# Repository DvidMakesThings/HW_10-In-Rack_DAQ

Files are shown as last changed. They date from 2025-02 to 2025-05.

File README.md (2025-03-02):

# DataForge-Pi - The Raspberry integrated DAQ Project



## Introduction

In the current market, finding a DAQ specifically designed for 10-inch racks is quite challenging. Most available options are tailored for 19-inch racks, which are significantly larger and not suitable for more compact setups. Recognizing this gap, I embarked on a project to create a DAQ solution that fits perfectly in a 10-inch rack while still providing all the necessary features and functionalities. The goal of this project is not only to address the size constraints but also to keep the costs low and make the design accessible to everyone. 

## Development Phases

| Phase | Status |
| --- | --- |
| **PCB Design & Prototyping** |  |
| **Design Review** |  |
| **Enclosure Design** |  |
| **Order PCB** |  |
| **Prototyping and Hardware Testing** |  |
| **Initial Firmware Development** |  |
| **Enclosure Testing & Ventilation**  |  |
| **Web-Based UI for Control** |  |
| **Power Logging & Alerts** |  |
| **Production Optimization** |  |

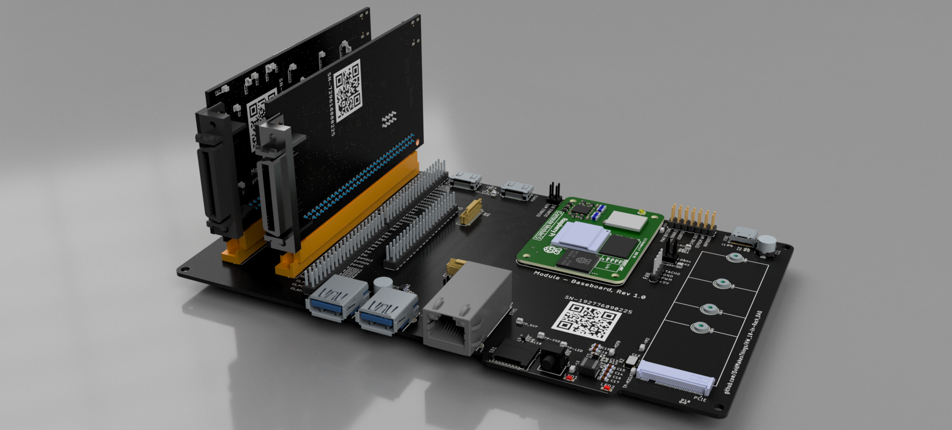
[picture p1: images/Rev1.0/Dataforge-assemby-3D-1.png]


## Features

Key features of the CM5 are as follows (for more details, refer to the [CM5 datasheet](docs/Datasheets/Raspberry-CM5_Datasheet.pdf)):

- Broadcom BCM2712, quad core Cortex-A76 (ARMv8) 64-bit SoC @ 2.4GHz
- Small Footprint 55mm × 40mm × 4.7mm module
  - 4 × M2.5 mounting holes
- 4kp60 HEVC decoder
- OpenGL ES 3.1 graphics, Vulkan 1.2
- Options for 2GB, 4GB, or 8GB LPDDR4-4267 SDRAM with ECC (see Appendix D)
- Options for 0GB (CM5Lite), 16GB, or 32GB eMMC flash memory (see Appendix D)
  - Peak eMMC bandwidth 400MBps (four times faster than previous Compute Modules)
- Option (see Appendix D) for certified radio module with:
  - 2.4 GHz, 5.0 GHz IEEE 802.11 b/g/n/ac wireless
  - Bluetooth 5.0, BLE
  - On board electronic switch to select between PCB trace or external antenna
- Gigabit Ethernet PHY supporting IEEE 1588
- 1 × PCIe 1-lane Host, Gen 2 (5Gbps)
- 1 × USB 2.0 port (high speed)
- 2 × USB 3.0 ports, supporting simultaneous 5Gbps operation
- Up to 30 × GPIO supporting either 1.8V or 3.3V signalling and peripheral options:
  - Up to 5 × UART
  - Up to 5 × I2C
  - Up to 5 × SPI
  - 1 × SDIO interface
  - 1 × DPI (parallel RGB display)
  - 1 × I2S
  - Up to 4 × PWM channels
  - Up to 3 × GPCLK outputs
- 2 × HDMI 2.0 ports (supports up to 4Kp60 on each port simultaneously)
- 2 × 4-lane MIPI ports
  - Supporting both DSI (display port) and CSI-2 (camera port)
- 1 × SDIO 2.0 (CM5Lite)
- Single +5V PSU input supports USB PD for up to 5A @ 5V
- Real-time clock (RTC), powered from external battery

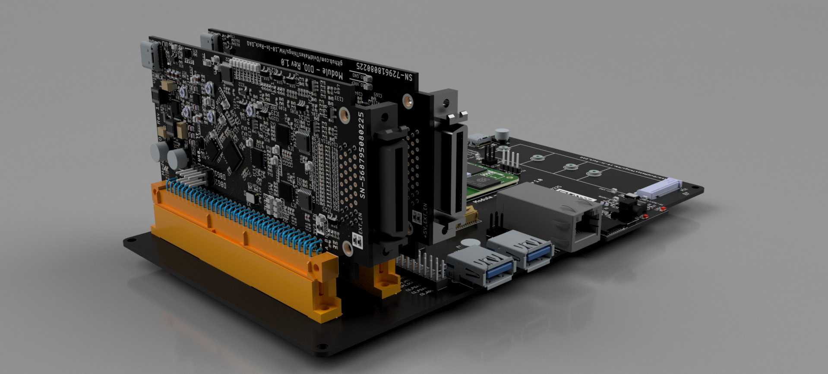
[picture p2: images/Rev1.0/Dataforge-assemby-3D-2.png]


## DAQ Specifications

### Analog Input (16 Channels)

The analog input section of the DAQ system is designed to provide high precision and flexibility for various applications. It features 16 channels of analog input, each capable of high-resolution data acquisition.

**Key Components:**
- **External 14-bit ADC:** The ADS9234RIRHBR is a 14-bit, 3.5-MSPS dual SAR ADC with simultaneous sampling, internal reference, and enhanced SPI, ensuring accurate and reliable measurements.
- **Multiplexers:** 2 × DG409 are employed for flexible channel selection, allowing the system to switch between different input channels efficiently.
- **Programmable Gain Amplifiers (PGA):** ADA4254ACPZ are used to provide scalable input ranges, enabling the system to handle a wide variety of signal amplitudes.

### Analog Output (8 Channels)

The analog output section is designed to provide precise and stable output signals. It features 8 channels of analog output, each capable of high-resolution signal generation.

**Key Components:**
- **External 16-bit DAC:** The DAC8568 is used for precision outputs, ensuring accurate and stable signal generation.
- **Operational Amplifiers:** TLV2372 are used for buffering and output stability, providing reliable and consistent performance.

### Digital IO (32 Channels)

The digital IO section is designed to provide versatile and robust digital input and output capabilities. It features 32 channels of digital IO, each capable of handling various voltage levels and signal types.

**Key Components:**
- **Bidirectional Voltage-Level Translators:** LSF0108-Q1 are used for multi-voltage compatibility, allowing the system to interface with different voltage levels.
- **Direct GPIO Support:** The RP2040 provides simple and robust design for direct GPIO support, ensuring reliable digital IO performance.

### Constants

- **ADC Sampling Rate:** 3.5 MSPS (Maximum sampling rate of ADS9234R)
- **ADC Nyquist Limit:** 1.75 MHz (Nyquist bandwidth for ADC)
- **PGA Bandwidth:** 10 MHz (Maximum bandwidth of ADA4254 at Gain = 1)
- **DG409 Transition Time:** 160 ns (Transition time for DG409)
- **ADA4254 Transition Time:** 200 ns (Transition time for ADA4254)

### Bandwidth for Each Gain Setting

The bandwidth for each gain setting is determined by the combination of the ADC's Nyquist limit and the PGA's frequency response. For gains less than or equal to 1, the bandwidth is capped by the ADC's Nyquist limit. For gains greater than 1, the bandwidth is limited by the PGA's frequency response.

- **Gain = 1/16:** Bandwidth = 1.75 MHz (Capped by ADC)
- **Gain = 1/8:** Bandwidth = 1.75 MHz (Capped by ADC)
- **Gain = 1/4:** Bandwidth = 1.75 MHz (Capped by ADC)
- **Gain = 1/2:** Bandwidth = 1.75 MHz (Capped by ADC)
- **Gain = 1:** Bandwidth = 1.75 MHz (Capped by ADC)
- **Gain = 2:** Bandwidth = 1.75 MHz (Capped by ADC)
- **Gain = 4:** Bandwidth = 1.75 MHz (Capped by ADC)
- **Gain = 8:** Bandwidth = 1.25 MHz (PGA Limited)
- **Gain = 16:** Bandwidth = 625 kHz (PGA Limited)
- **Gain = 32:** Bandwidth = 312.5 kHz (PGA Limited)
- **Gain = 64:** Bandwidth = 156.25 kHz (PGA Limited)
- **Gain = 128:** Bandwidth = 78.125 kHz (PGA Limited)

### Notes

- For Gains ≤ 1, bandwidth is capped by ADC's Nyquist limit (1.75 MHz).
- For Gains > 1, bandwidth is limited by the PGA's frequency response.
- Transition delays (DG409 + ADA4254) are factored into the calculation.

### Input Ranges for Different Gains

The input ranges for different gain settings are determined by the reference voltage (VREF), positive supply voltage (V+), and negative supply voltage (V-). For this system, VREF is set to 2.5V, V+ is set to +12V, and V- is set to -12V.

| Gain | Differential Input Range (±V) | Positive Input Range (0 to V) | Negative Input Range (0 to -V) | Max Bandwidth (Hz) |
|---|---|---|---|---|
| 1/16 | ±80.0 | 0 to 40.0 | 0 to -40.0 | 1,750,000 |
| 1/8  | ±40.0 | 0 to 20.0 | 0 to -20.0 | 1,750,000 |
| 1/4  | ±20.0 | 0 to 10.0 | 0 to -10.0 | 1,750,000 |
| 1/2  | ±10.0 | 0 to 5.0 | 0 to -5.0 | 1,750,000 |
| 1 | ±5.0 | 0 to 2.5 | 0 to -2.5 | 1,750,000 |
| 2 | ±2.5 | 0 to 1.25 | 0 to -1.25 | 1,750,000 |
| 4 | ±1.25 | 0 to 0.625 | 0 to -0.625 | 1,750,000 |
| 8 | ±0.625 | 0 to 0.3125 | 0 to -0.3125 | 1,250,000 |
| 16 | ±0.3125 | 0 to 0.15625 | 0 to -0.15625 | 625,000 |
| 32 | ±0.15625 | 0 to 0.078125 | 0 to -0.078125 | 312,500 |
| 64 | ±0.078125 | 0 to 0.0390625 | 0 to -0.0390625 | 156,250 |
| 128  | ±0.0390625 | 0 to 0.01953125 | 0 to -0.01953125 | 78,125 |

## Getting Started

Refer to the datasheets and manuals in the `docs` folder for detailed information on the components and usage instructions.

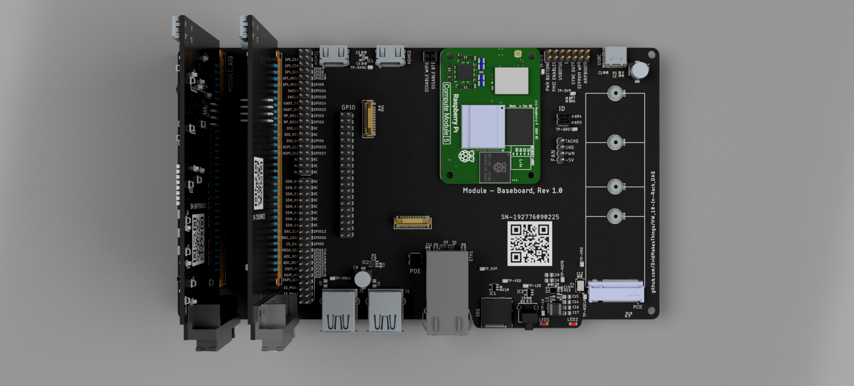
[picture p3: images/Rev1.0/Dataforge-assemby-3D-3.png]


## License

This project is licensed under the GPL3 License. See the LICENSE file for details.

## Contact

For questions or feedback:

- Email: s.dvid@hotmail.com
- GitHub: [DvidMakesThings](https://github.com/DvidMakesThings)

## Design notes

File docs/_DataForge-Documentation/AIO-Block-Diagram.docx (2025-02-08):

+12V -12V

+5V +3.3V

0-5V OUT

+/-12V OUT

BUFFER

IN

OUT

BUFFER

IN

OUT

+/- IN0-7

+/- IN8-15

DAC

DAC-IO
SPI

OUT 0-3
OUT 4-7

VREF

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
VREF

+12V -12V +3.3V

ANALOG SW

OUT
DIO

IN

ANALOG SW

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
MISO SEL

SEL

SDOA
SDOB

MISO

RP2040

ADC-IO

SPI0

SDO

MISO-SEL

DAC-IO

DEBUG

SPI1

ADC

VBUS
+12V
-12V
+5V

UART0
SWIO

GPIO INTERFACE

DEBUG

SPI1

ADC-IO

SPI0

SDO

SEL

DAC-IO

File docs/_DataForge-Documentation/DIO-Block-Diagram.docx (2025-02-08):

+5V SUPPLY

+3.3V SUPPLY

GPIO INTERFACE

DEBUG

SPI1

LEVEL SEL

SPI0

DIO-RST

DIO-EN

UART0
SWIO

+5V SUPPLY

VBUS

LEVEL SEL

LS

+5V

+3.3V

OUT

DIOH

SPI

RST

OUT

LEVEL TRANSLATOR

EN

IN

VREF

OUT

LEVEL TRANSLATOR

EN

IN

VREF

OUT

LEVEL TRANSLATOR

EN

IN

VREF

OUT

LEVEL TRANSLATOR

EN

IN

VREF

OUT

RP2040

LEVEL SEL

SPI0

DIO-RST

DIO-EN

DEBUG

SPI1

ADC

DIOL

SPI

RST

OUT

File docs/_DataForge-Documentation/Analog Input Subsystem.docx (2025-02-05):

# Analog Input Subsystem

# 1. Introduction

This document provides a detailed overview of the Analog Input (AI) subsystem of the DAQ system, focusing on signal acquisition, amplification, filtering, and communication with the ADC. It covers key components, signal flow, and considerations for optimal performance.

# 2. System Overview

The Analog Input Subsystem consists of:

- 16 Differential Analog Inputs (AI)
- Programmable Gain Amplifiers (PGA) for signal conditioning
- Multiplexers for channel selection
- High-speed 14-bit ADC for conversion
- SPI communication for data transfer
- Power distribution and filtering

# 3. Analog Input (16 Channels)

The analog input section of the DAQ system is designed to provide high precision and flexibility, capable of acquiring signals from various sources.

## 3.1 Key Components

- External 14-bit ADC: ADS9234RIRHBR, a 14-bit, 3.5-MSPS dual SAR ADC with simultaneous sampling, internal reference, and enhanced SPI for high-speed acquisition.
- Multiplexers: 2 × DG409 for channel selection, enabling flexible signal routing to the ADC.
- Programmable Gain Amplifiers (PGA): ADA4254ACPZ for scalable input ranges, ensuring adaptability to different signal levels.

## 3.2 ADC Communication & Control

- SPI Interface:
  - SCLK (Clock Signal)
  - MOSI (Master Out Slave In)
  - MISO (Master In Slave Out)
  - CS (Chip Select)
- Control Signals:
  - ADC_RDY: Data ready indication
  - ADC_RST: Reset signal
  - MISO_SEL: Selects the correct SPI MISO line

## 3.3 Analog Input Switching Mechanism (Differential and Single-Ended Mode)

To maximize the flexibility of the system while maintaining accurate signal acquisition, a DG409 multiplexer is used to route the selected input signal to the ADA4254 programmable gain amplifier (PGA) before being fed into the ADS9234 ADC.

Each DG409 consists of four normally open SPST switches that can be controlled digitally. The AI+ signals are routed through the upper switch bank, while the corresponding AI- signals are routed through the lower switch bank. For differential measurements, both AI+ and AI- channels are selected. For single-ended measurements, either AI+ or AI- can be selected, while the unselected input is connected to ground.

## 3.4 Channel Selection Control (Differential and Single-Ended)

The DG409 multiplexer allows the selection of one of four differential input pairs or a single-ended configuration. The selection is made via two digital control inputs (A0, A1), which follow the logic below:

Differential Input Mode Single-Ended Input Mode

A1 | A0 | Selected AI+ / AI- Pair
0 | 0 | AI1+ / AI2-
0 | 1 | AI3+ / AI4-
1 | 0 | AI5+ / AI6-
1 | 1 | AI7+ / AI8-

A1 | A0 | Selected Input | Other Input
0 | 0 | AI1+ or AI2- | GND
0 | 1 | AI3+ or AI4- | GND
1 | 0 | AI5+ or AI6- | GND
1 | 1 | AI7+ or AI8- | GND

By setting the control signals A0 and A1 correctly, any of the available differential or single-ended inputs can be connected to the PGA and ADC. The multiplexer transitions occur within 160ns, ensuring minimal signal delay.

## 3.5 Software Control of Channel Selection

In the software, the channel selection is managed by setting the GPIO pins connected to the DG409 control inputs (A0, A1). The selection process follows these steps:

1. Disable Data Acquisition: Before switching channels, the ADC sampling process is halted to prevent incorrect readings during transitions.
2. Set Multiplexer Control Lines: The microcontroller sets the GPIO pins corresponding to A0 and A1 based on the required channel.
3. Configure for Single-Ended or Differential Mode: If single-ended mode is selected, the corresponding AI- or AI+ input is connected to ground in software.
4. Delay for Settling Time: A short delay (~200ns) is introduced to allow the multiplexer switches to stabilize.
5. Enable Data Acquisition: Once the multiplexer output has stabilized, ADC sampling resumes.

This function allows dynamic switching between differential and single-ended configurations, with the ability to choose whether AI+ or AI- is used as the active signal.

## 3.6 PGA and ADC Interaction

Once a selected differential input signal is passed through the DG409 multiplexer, it is fed into the ADA4254 programmable gain amplifier (PGA). The gain of the PGA can be controlled dynamically based on system requirements to optimize signal-to-noise ratio before it is sent to the ADS9234 ADC for digitization.

## 3.7 Bandwidth for Each Gain Setting

The bandwidth is determined by the ADC's Nyquist limit and the PGA's frequency response. Lower gains maintain the ADC's full bandwidth, while higher gains are limited by the PGA.

Gain | Max Bandwidth (Hz)
1/16 | 1,750,000
1/8 | 1,750,000
1/4 | 1,750,000
1/2 | 1,750,000
1 | 1,750,000
2 | 1,750,000
4 | 1,750,000
8 | 1,250,000
16 | 625,000
32 | 312,500
64 | 156,250
128 | 78,125

## 3.8 Input Ranges for Different Gains

The input ranges are defined by the reference voltage (VREF = 2.5V), positive supply voltage (+12V), and negative supply voltage (-12V).

Gain | Differential Input Range (±V) | Positive Input Range (0 to V) | Negative Input Range (0 to -V)
1/16 | ±80.0 | 0 to 40.0 | 0 to -40.0
1/8 | ±40.0 | 0 to 20.0 | 0 to -20.0
1/4 | ±20.0 | 0 to 10.0 | 0 to -10.0
1/2 | ±10.0 | 0 to 5.0 | 0 to -5.0
1 | ±5.0 | 0 to 2.5 | 0 to -2.5
2 | ±2.5 | 0 to 1.25 | 0 to -1.25
4 | ±1.25 | 0 to 0.625 | 0 to -0.625
8 | ±0.625 | 0 to 0.3125 | 0 to -0.3125
16 | ±0.3125 | 0 to 0.15625 | 0 to -0.15625
32 | ±0.15625 | 0 to 0.078125 | 0 to -0.078125
64 | ±0.078125 | 0 to 0.0390625 | 0 to -0.0390625
128 | ±0.0390625 | 0 to 0.01953125 | 0 to -0.01953125

# 4. Power Subsystem for Analog Input

## 4.1 Power System Overview

The analog input subsystem requires multiple voltage levels to operate correctly. The ADC and SPI communication rely on a stable 3.3V power rail, while the PGA and analog input circuits need ±12V for proper operation. To generate these voltages, a combination of a boost converter and LDO regulators is used.

## 4.2 Boost Converter (5V to ±14V)

The TPS65131 is a dual-output DC-DC converter that efficiently converts a 5V input to ±14V, ensuring stable and isolated power for the high-performance analog circuits. The positive and negative voltage rails are generated using a single inductor topology, reducing PCB space and complexity. The output is stabilized using low-ESR capacitors (22µF and 10µF), ensuring minimal ripple.

## 4.3 LDO Regulation (±14V to ±12V)

The ±14V rails generated by the boost converter are further regulated using the TPS7A39, a precision low-noise LDO regulator. This step ensures that the analog circuits receive clean and low-ripple ±12V supplies. The regulator uses bulk 22µF capacitors for stable operation, with 100nF decoupling capacitors placed near the power pins of the PGA and ADC to prevent noise coupling.

## 4.4 Power Distribution Considerations

To ensure optimal performance, the power system is designed with:

- Separate ground planes for analog and digital sections to minimize interference.
- High-frequency decoupling capacitors near ICs to suppress transient noise.
- Low dropout regulators to improve power efficiency and thermal management.
- Current limiting and ESD protection at the power input to prevent damage from transient spikes or electrical surges.

# 5. Summary

This document focuses exclusively on the Analog Input Subsystem of the DAQ system, covering:

- 16 AI differential inputs with signal conditioning.
- PGA and multiplexer configurations for flexible input selection.
- SPI-based ADC communication and control logic.
- A well-structured power system, including boost conversion and LDO regulation.

This modular approach ensures seamless integration into the full DAQ system while maintaining signal integrity and accuracy.

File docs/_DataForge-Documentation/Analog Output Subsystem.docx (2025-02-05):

# Analog Output Subsystem:

# OPA192 & OPA197 Integration

# 1. Introduction

This document presents a detailed design for the analog output stage of a Data Acquisition (DAQ) system, ensuring accurate signal conditioning, stability, and robustness.

The DAQ outputs are classified into two voltage stages:

- DAC0-3 (3.3V Stage)
  - Uses OPA192 as the buffer op-amp.
  - Output range: 0V to 3.3V.
- DAC4-7 (±12V Stage)
  - Uses OPA197 for high-voltage amplification.
  - Output range: -12V to +12V.

## 1.1. Design Objectives

The core objectives of this design include:

1. Accurate DAC output scaling
2. Ensuring stability with capacitive loads
3. Consistent bandwidth (~100 kHz) across both stages
4. Minimized voltage drop across R_ISO
5. Optimized resistor values for precise scaling

# 2. DAC8568 Output Scaling for 3.3V and ±12V Stages

The DAC8568 generates a 0V to 2.5V output, which must be amplified and shifted to match the respective voltage stages.

## 2.1. Output Calculation

For a generalized output scaling formula, the output voltage is given by:

V_(OUT) =(1+(R_(FB))/(R_(G2))+(R_(FB))/(R_(G1)))V_(DAC) -((R_(FB))/(R_(G2)))V_(REF)

Where:

- V_(DAC) = DAC output voltage (0 to 2.5V)
- V_(REF) = 2.5V DAC reference
- R_(FB) = Feedback resistor
- R_(G1) , R_(G1) = Gain resistors

The resistor network is designed separately for each voltage stage.

# 3. DAC8568 Output Scaling for 3.3V Stage

The 3.3V stage (DAC0-3) uses OPA192 in a non-inverting amplifier configuration.

## 3.1. Gain Calculation

The gain is:

G=(V_(OUT_(max)) -V_(OUT_(min)))/(V_(DAC_(max)) -V_(DAC_(min)))

G=(3.3V-0V)/(2.5V-0V)=1.32

## 3.2. Resistor Selection

For a non-inverting amplifier, the gain is:

G=1+(R_F)/(R_G)

Choosing R_G =10kΩ :

1.32=1+(R_F)/(10kΩ)

R_F =(1.32-1) ∙10kΩ=3.2kΩ

## 3.3. Output Resolution Calculation

- DAC resolution:

Resolution_(DAC) =(V_(REF))/(2^16)=(2.5V)/65536≈0.038mV

- Scaled output resolution:

Resolution_(OUT) = Resolution_(DAC) ∙G=0.038mV∙1.32 ≈0.05mV

## 3.4. Final Resistor Values

Component | Value
R_F | 3.2kΩ
R_G | 10kΩ

# 4. DAC8568 Output Scaling for ±12V Stage

The ±12V stage (DAC4-7) uses OPA197 to achieve high-voltage amplification.

## 4.1. Gain Calculation

The gain is:

G=(V_(OUT_(max)) -V_(OUT_(min)))/(V_(DAC_(max)) -V_(DAC_(min)))

G=(12V-(-12V))/(2.5V-0V)=(24V)/(2.5V)=9.6

## 4.2. Resistor Selection

For a non-inverting amplifier, the gain is:

G=1+(R_F)/(R_G)

Choosing R_G =10kΩ :

9.6=1+(R_F)/(10kΩ)

R_F =(9.6-1) ∙10kΩ=86kΩ

## 4.3. Output Resolution Calculation

Scaled output resolution:

Resolution_(OUT) = Resolution_(DAC) ∙G=0.038mV∙9.6 ≈0.3648mV

## 4.4. Final Resistor Values

Component | Value
R_F | 86kΩ
R_G | 10kΩ

# 5. Stability Considerations

## 5.1. OPA192 (3.3V Stage)

- Low-power op-amp with 1 MHz GBW.
- Requires R_(ISO) for stability with higher capacitive loads.
- Chosen values:
  - R_(ISO) =68Ω
  - C_(LOAD) =20nF

## 5.2. OPA197 (±12V Stage)

- Precision op-amp with 2.5 MHz GBW.
- Stabilized by R_ISO for capacitive loads.
- Chosen values:
  - R_(ISO) =110Ω
  - C_(LOAD) =12nF

# 6. Load Stability & Voltage Drop Analysis

The cutoff frequency for stability is:

f_c =1/(2 π R_(ISO) C_(LOAD))

For the 3.3V stage:

f_c =1/(2∙π∙ 68 ∙20nF)≈117 kHz

For the ±12V stage:

f_c =1/(2∙π∙110 ∙12nF)≈120 kHz

Voltage drop across R_(ISO) :

V_(drop) =I_(load) ∙R_(ISO)

For 5mA output current:

- OPA192 (3.3V Stage, R_(ISO) =68Ω )

V_(drop_(3V3)) =5mA∙68Ω=0.34V

- OPA197 (±12V Stage, R_(ISO) =110Ω )

V_(drop_(12V)) =5mA∙110Ω=0.55V

# 7. Final Optimized Circuit

## 7.1. Parameter Summary

DAC Channel | Op-Amp | Supply Voltage | Output Voltage Range | R_(ISO) | C_(LOAD) | Cutoff Frequency (kHz)
DAC0-3 | OPA192 | 5V | 0V to 3.3V | 68Ω | 20nF | 117 kHz
DAC4-7 | OPA197 | ±12V | -12V to +12V | 110Ω | 12nF | 120 kHz

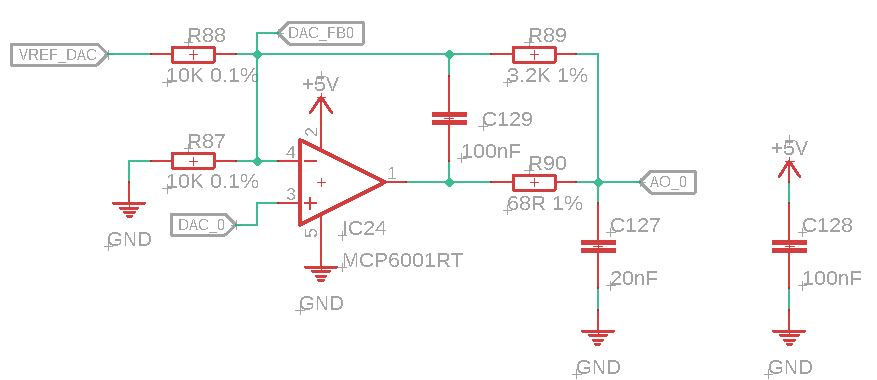
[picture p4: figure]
A képen diagram, szöveg, sor, Diagram látható Előfordulhat, hogy a mesterséges intelligencia által létrehozott tartalom helytelen.
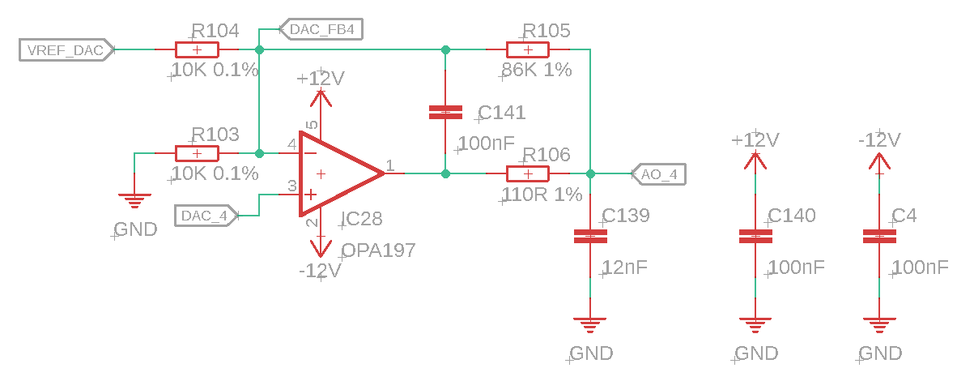
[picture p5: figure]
A képen diagram, szöveg, sor, Tervrajz látható Előfordulhat, hogy a mesterséges intelligencia által létrehozott tartalom helytelen.

# 8. Purpose of the 10kΩ Pulldown Resistors

The pulldown resistors serve a critical role in ensuring signal stability by preventing the op-amp’s inverting input from floating if the DAC output becomes high impedance (tri-stated or powered down). A floating inverting input can result in:

- Op-amp instability or oscillations
- Increased noise sensitivity
- Unexpected voltage drift due to leakage currents

To evaluate whether the 10kΩ resistors are necessary, we analyze their voltage effect and impact on circuit stability for both the 3.3V and ±12V output stages.

## 8.1. Voltage Division & Leakage Current Analysis

If the DAC output enters high impedance mode (open circuit), the pulldown resistor determines the voltage at the op-amp's inverting input.

## 8.2. Calculation for the 3.3V Stage (OPA192)

- Op-amp: OPA192 (low-power, rail-to-rail, 5V single-supply)
- Pulldown resistor: R_(PD) =10kΩ
- DAC reference voltage: V_(DAC_(max)) =2.5V, V_(DAC_(min)) =0V
- Op-amp bias current (typical): I_B =1pA
- Leakage current estimate I_(leak) =10nA (conservative assumption)

Voltage at the inverting input when DAC is in high-Z mode:

V_(IN-) = R_(PD) I_(leak) =10kΩ ∙10nA=0.1mV

## 8.3. Calculation for the ±12V Stage (OPA197)

- Op-amp: OPA197 (precision, ±12V supply)
- Pulldown resistor: R_(PD) =100kΩ
- DAC reference voltage: V_(DAC_(max)) =2.5V, V_(DAC_(min)) =0V
- Op-amp bias current (typical): I_B =10pA
- Leakage current estimate I_(leak) =20nA

Voltage at the inverting input when DAC is in high-Z mode:

V_(IN-) = R_(PD) I_(leak) =100kΩ ∙20nA=2mV

## 8.4 Impact on Stability & Frequency Response

The inverting input is highly sensitive. Without the pulldown resistor:

- Any residual charge on the PCB traces could cause voltage drift.
- Leakage currents from the DAC or op-amp could accumulate, shifting the voltage.
- Noise from adjacent signals could capacitively couple into the floating node, leading to oscillations.

Adding R_(PD) prevents floating and keeps the circuit deterministic even if the DAC is disabled.

## 8.5. Power Dissipation Analysis

For continuous operation, power consumption due to the pulldown resistors is:

P=(V^2)/R

The 3.3V Stage:

P=(5V^2)/(10kΩ)=2.5mW

The ±12V Stage:

P=(12V^2)/(100kΩ)=1.44mW

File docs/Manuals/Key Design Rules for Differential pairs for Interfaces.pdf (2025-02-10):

## High-Speed Differential Pair Routing Guidelines

Interface | Type | Signal Names Pair Matching
Tolerance

Inter-Pair
Matching
Tolerance

Additional
Notes
USB 2.0 | Differential | DP_N, DP_P | ±150 mil | Not required | Keep traces short, avoid vias
USB 3.0 | Differential | SSRX_N, SSRX_P / SSTX_N, SSTX_P | ±2 mil | ±5 mil | Avoid stubs, tightly controlled impedance
USB 3.1/3.2 | Differential | SSRX_N, SSRX_P / SSTX_N, SSTX_P | ±2 mil | ±5 mil | Minimize vias, length matching critical
USB4 / Thunderbolt 3 | Differential | HSRX_N, HSRX_P / HSTX_N, HSTX_P | ±1 mil | ±3 mil | Use well- matched controlled impedance stackup
Ethernet 100BASE-TX | Differential | TD_N, TD_P / RD_N, RD_P | ±50 mil | ±100 mil | Terminate properly, avoid large trace gaps
Ethernet 1000BASE-T | Differential | TX1_N, TX1_P / TX2_N, TX2_P / TX3_N, TX3_P / TX4_N, TX4_P | ±5 mil | ±10 mil | All pairs must be matched for delay skew
Ethernet 10GBASE-T | Differential | TXA_N, TXA_P / TXB_N, TXB_P / TXC_N, TXC_P / TXD_N, TXD_P | ±2 mil | ±5 mil | Use high- quality PCB material
HDMI 1.4 | Differential | TMDS0_N, TMDS0_P / TMDS1_N, TMDS1_P / TMDS2_N, TMDS2_P / TMDS_CK_N, TMDS_CK_P | ±5 mil | ±20 mil | Keep CLK pair shorter than data pairs
HDMI 2.0 | Differential | TMDS0_N,
TMDS0_P /
TMDS1_N,
TMDS1_P /
TMDS2_N,
TMDS2_P /
±2 mil | ±10 mil | All lanes must
be lengthmatched

TMDS_CK_N,
TMDS_CK_P
DisplayPort
1.2

Differential ML0_N, ML0_P
/ ML1_N,
ML1_P /
AUX_N, AUX_P
±3 mil | ±10 mil | Minimize skew
between lanes

DisplayPort
2.0

Differential ML0_N, ML0_P
/ ML1_N,
ML1_P /
AUX_N, AUX_P
±2 mil | ±5 mil | Very strict
inter

-pair
matching
PCIe Gen1/2 | Differential | PCIE_RX_N,
PCIE_RX_P /
PCIE_TX_N,
PCIE_TX_P
±5 mil | ±20 mil | Avoid
impedance
discontinuities
PCIe Gen3 | Differential | PCIE_RX_N,
PCIE_RX_P /
PCIE_TX_N,
PCIE_TX_P
±2 mil | ±10 mil | Tighter
matching than
Gen1/2
PCIe Gen4 | Differential | PCIE_RX_N,
PCIE_RX_P /
PCIE_TX_N,
PCIE_TX_P
±1 mil | ±5 mil | Low

-loss PCB
materials
recommended
PCIe Gen5 | Differential | PCIE_RX_N,
PCIE_RX_P /
PCIE_TX_N,
PCIE_TX_P
±0.5 mil | ±2 mil | Extremely tight
tolerance, use
high

-speed
stackup
SATA 3.0 | Differential | SATA_TX_N,
SATA_TX_P /
SATA_RX_N,
SATA_RX_P
±5 mil | ±20 mil | Shortest
possible path,
avoid vias
SAS 12G | Differential | SAS_TX_N,
SAS_TX_P /
SAS_RX_N,
SAS_RX_P
±2 mil | ±5 mil | Keep
differential
impedance
strict
MIPI DSI/CSI | Differential | DSID0_N

,
DSID0_P

/
DSID1_N

,
DSID1_P

/
DSID2_N

,
DSID2_P

/
DSID3_N

,
DSID3_P

/
DSIC_N

,
DSIC_P
±2 mil | ±10 mil | Use matched trace routing for high -speed
LVDS | Differential | LVDS0_N,
LVDS0_P /
LVDS1_N,
LVDS1_P
±5 mil | ±20 mil | Terminate
correctly at
receiver

General Routing Guidelines:
1. Use an impedance calculator (based on your stackup) to determine trace width & spacing.
2. Keep differential pairs tightly coupled (avoid large gaps between P/N).
3. Minimize vias—every via adds impedance discontinuity.
4. Match each pair within tolerance to ensure proper signal integrity.
5. Inter-pair matching is critical for multi-lane interfaces (Ethernet, HDMI, PCIe, DP).
6. Avoid stubs—use direct traces whenever possible.

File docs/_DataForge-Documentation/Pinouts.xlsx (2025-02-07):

D-Sub Micro-D Connector |  | MAB64 Connector |  |  |  | RP2040
1 | V-EXT | A1 | +3.3V | B1 | +3.3V | GPIO0 | UART0_RX
2 | AI_0+ | A2 | SPI0_CS0 | B2 | SPI0_CS3 | GPIO1 | UART0_TX
3 | AI_1- | A3 | SPI0_CS1 | B3 | SPI0_SCK | GPIO2 | SPI0_SCK
4 | AI_2+ | A4 | SPI0_CS2 | B4 | SPI0_MOSI | GPIO3 | SPI0_MOSI
5 | AI_3- | A5 | SPI0_SCK | B5 | SPI0_MISO | GPIO4 | SPI0_MISO
6 | AI_4+ | A6 | SPI0_MOSI | B6 | NC | GPIO5 | SPI0_CS0
7 | AI_5- | A7 | SPI0_MISO | B7 | NC | GPIO6 | SPI0_CS1
8 | AI_6+ | A8 | +5V | B8 | +5V | GPIO7 | SPI0_CS2
9 | AI_7- | A9 | +5V | B9 | +5V | GPIO8 | ADC_RDY
10 | AI_8+ | A10 | GND | B10 | GND | GPIO9 | ADC_RST
11 | AI_9- | A11 | ADC_RDY | B11 | NC | GPIO10 | SPI1_SCK
12 | AI_10+ | A12 | ADC_RST | B12 | DAC_LDAC | GPIO11 | SPI1_MOSI
13 | AI_11- | A13 | MISO_SEL | B13 | DAC_CLR | GPIO12 | SPI1_MISO
14 | AI_12+ | A14 | GND | B14 | GND | GPIO13 | SPI1_CS
15 | AI_13- | A15 | GND | B15 | GND | GPIO14 | DAC_LDAC
16 | AI_14+ | A16 | GND | B16 | GND | GPIO15 | DAC_CLR
17 | AI_15- | A17 | SDO_A_0 | B17 | NC | GPIO16 | SDO_A_0
18 | GND | A18 | SDO_A_1 | B18 | RP2040-RST | GPIO17 | SDO_A_1
19 | GND | A19 | SDO_A_2 | B19 | GND | GPIO18 | SDO_A_2
20 | VBUS | A20 | SDO_A_3 | B20 | UART0_RX | GPIO19 | SDO_A_3
21 | AO_0 | A21 | SDO_B_0 | B21 | UART0_TX | GPIO20 | SDO_B_0
22 | GND | A22 | SDO_B_1 | B22 | GND | GPIO21 | SDO_B_1
23 | AO_1 | A23 | SDO_B_2 | B23 | SWCLK | GPIO22 | SDO_B_2
24 | GND | A24 | SDO_B_3 | B24 | SWDIO | GPIO23 | SDO_B_3
25 | AO_2 | A25 | GND | B25 | GND | GPIO24 | MISO_SEL
26 | GND | A26 | SPI1_MISO | B26 | SPI1_MISO | GPIO25 | SPI0_CS3
27 | AO_3 | A27 | SPI1_MOSI | B27 | SPI1_MOSI | GPIO26/ADC0 | ADC_VUSB
28 | GND | A28 | SPI1_SCK | B28 | SPI1_SCK | GPIO27/ADC1 | ADC_12VP
29 | AO_4 | A29 | SPI1_CS | B29 | SPI1_CS | GPIO28/ADC2 | ADC_12VN
30 | GND | A30 | GND | B30 | GND | GPIO29/ADC3 | ADC_5VP
31 | AO_5 | A31 | GND | B31 | GND
32 | GND | A32 | GND | B32 | GND
33 | AO_6
34 | GND
35 | AO_7
36 | GND

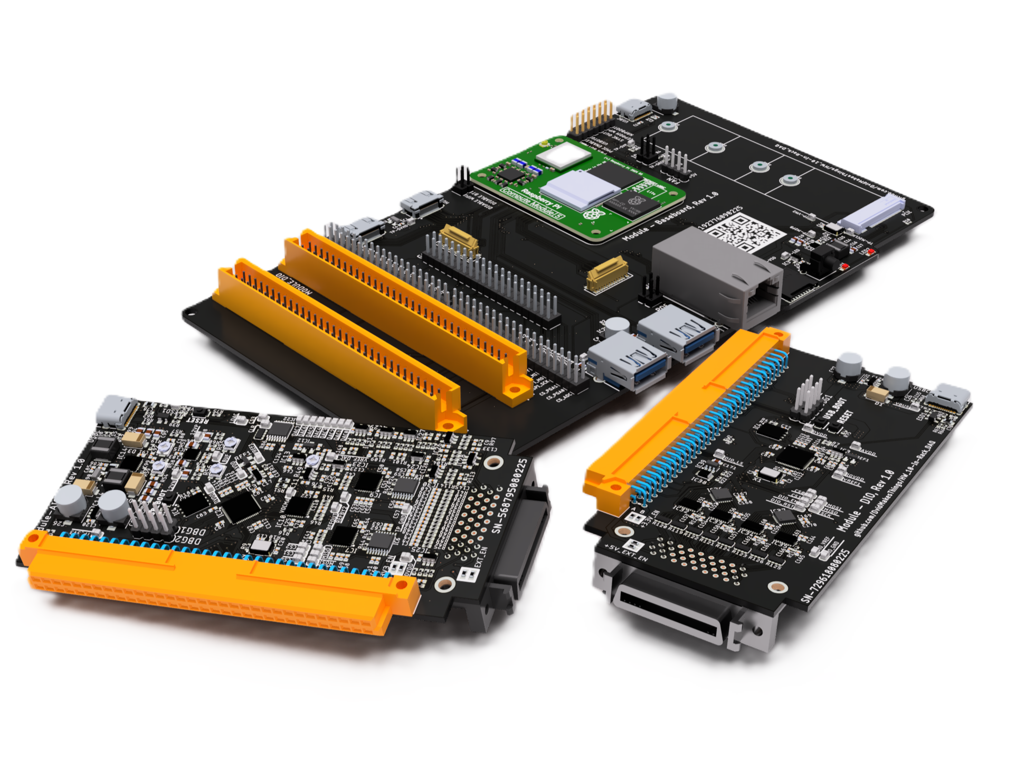
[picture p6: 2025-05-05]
images/dataforge_render1.png

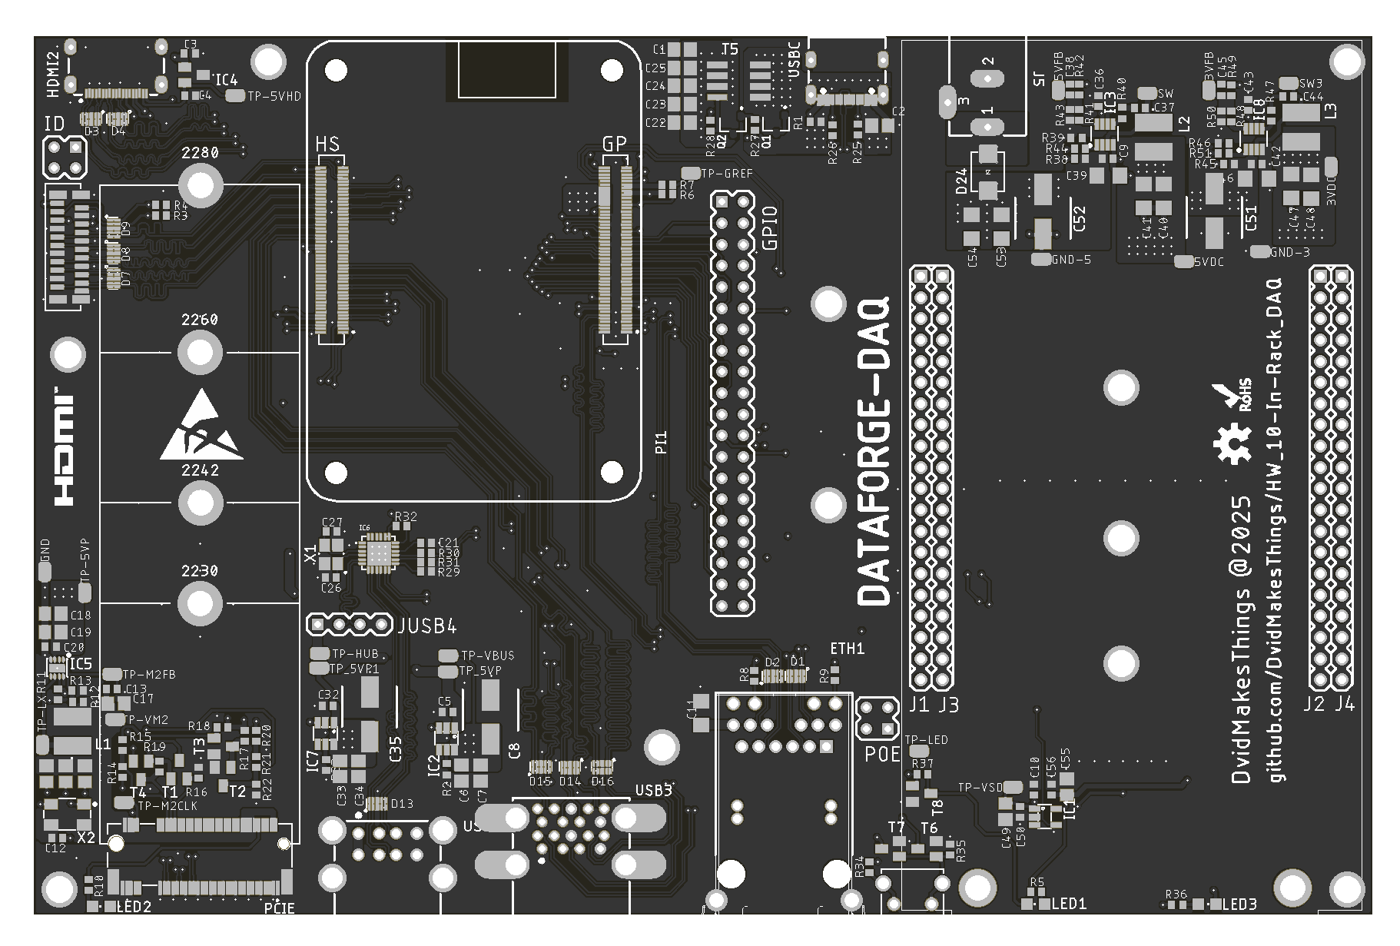
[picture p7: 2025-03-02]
images/Module_BaseBoard _2.0_Top.png

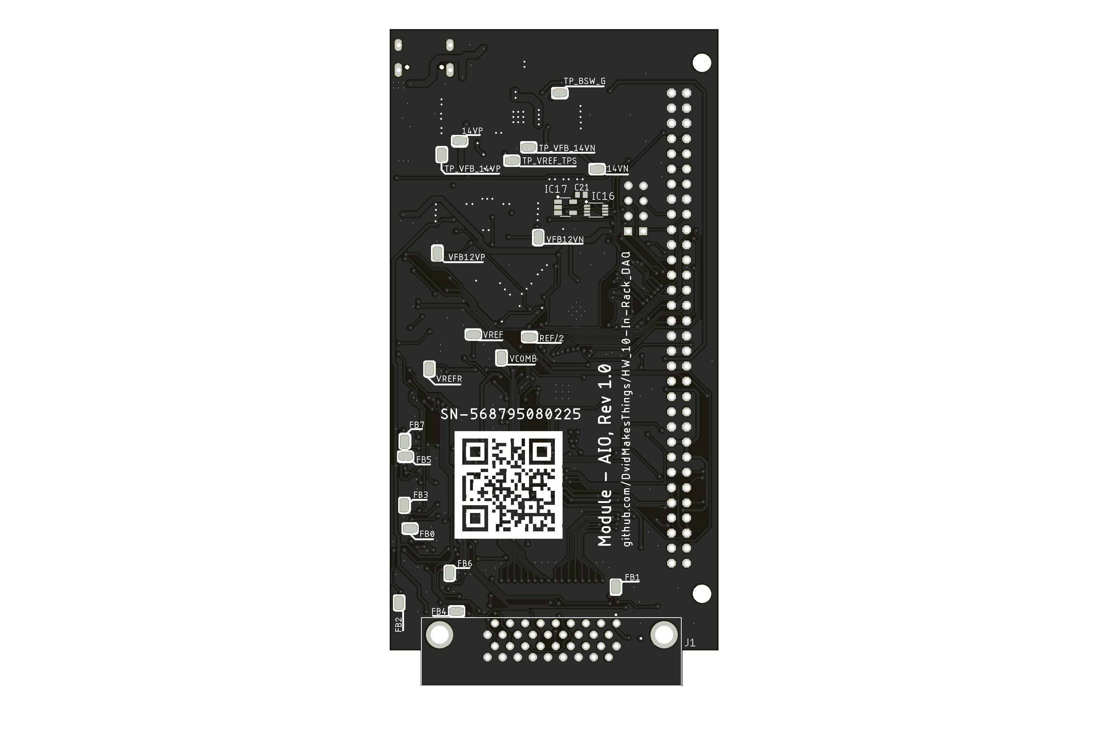
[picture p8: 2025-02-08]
images/Rev1.0/Module_AIO_bottom.png

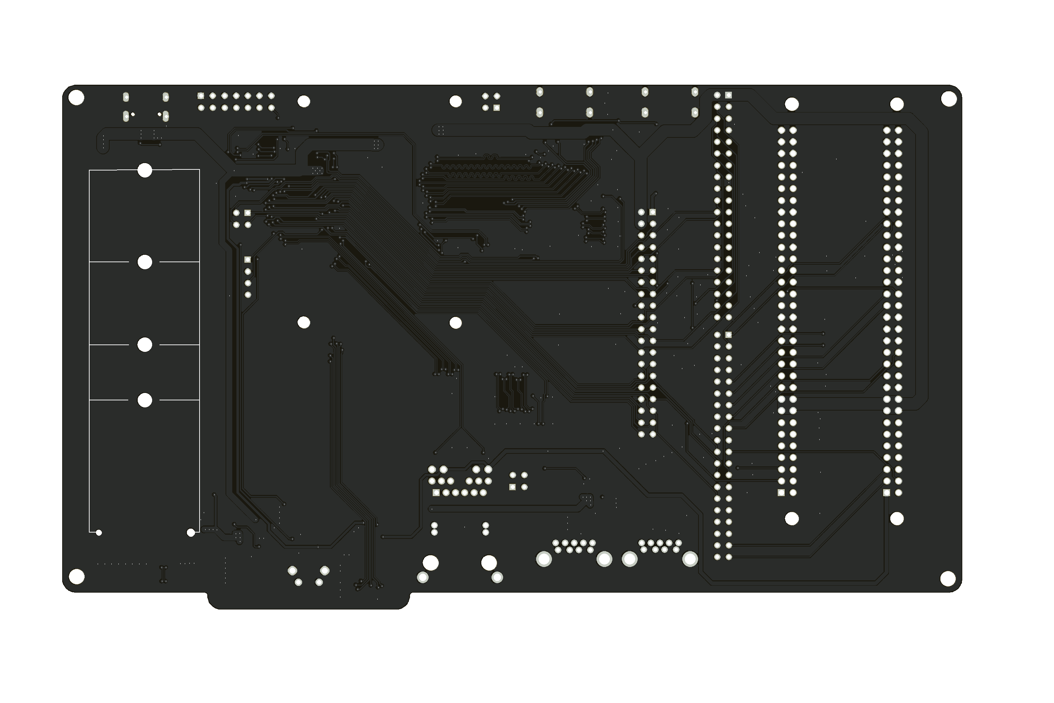
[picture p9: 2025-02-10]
images/Rev1.0/Module_BaseBoard_Bottom.png

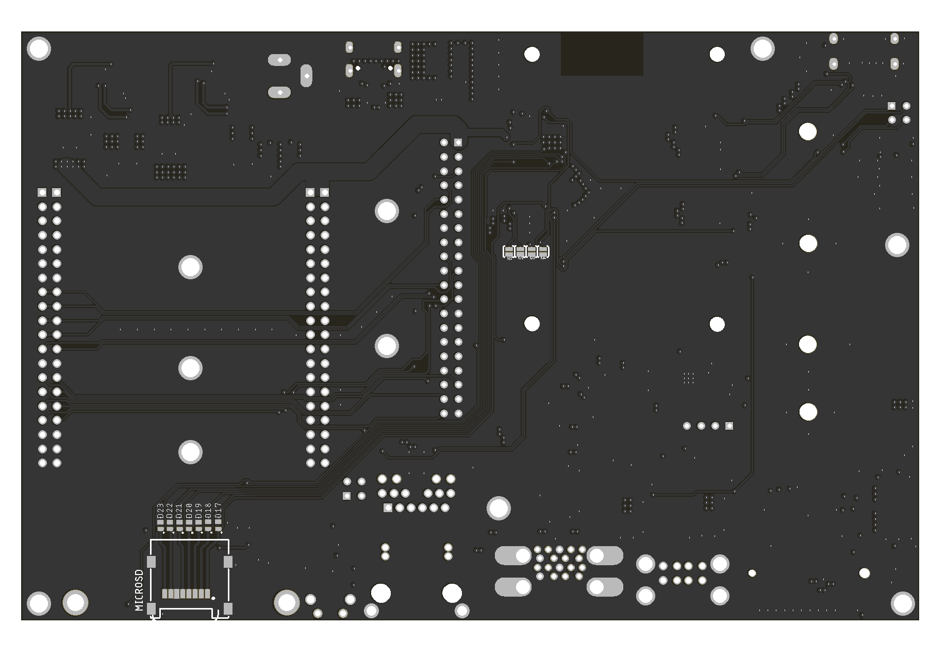
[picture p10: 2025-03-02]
images/Module_BaseBoard _2.0_Bottom.png

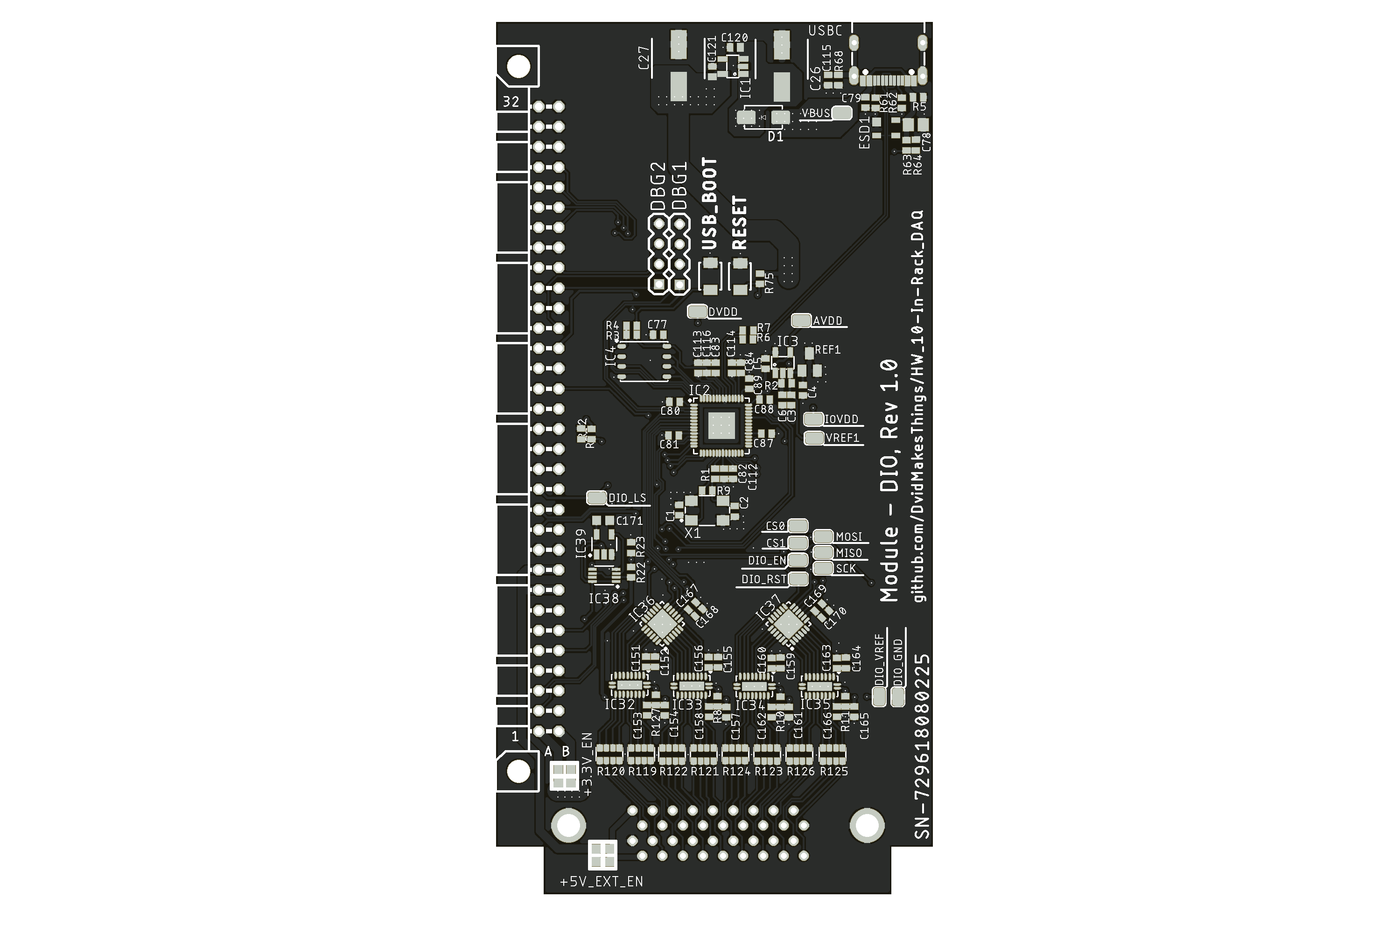
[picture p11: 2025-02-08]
images/Rev1.0/Module_DIO_top.png

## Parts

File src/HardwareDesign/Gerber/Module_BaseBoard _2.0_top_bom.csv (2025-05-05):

Comment | Designator | Footprint | LCSC Part #
 | IC6 | QFN24
 | LED2 | CHIPLED_0805
 | PI1 | CM5
0R | R6 | 0402
1K | R5 R10 R34 R35 R36 | 0402
2.2K | R16 | 0402
2.2K 1% | R1 R3 R4 R13 | 0402
2.2R | R30 R31 | 0402
3.6K 1% | R21 | 0402
4.2uH | L3 | SRR5228A
4.7nF | C13 | C0402
4.9uH | L2 | SRR5228A
6.8K 1% | R22 | 0402
7.5K | R43 R46 | 0402
9.09K | R39 | 0402
10K | R14 R17 R18 R19 | 0402
10K 1% | R12 | 0402
10R | R40 R47 | 0402
10pF | C26 C27 | C0402
10uF | C2 C6 C7 C14 C15 C16 C17 C18 C19 C23 C24 C25 C33 C34 C49 | C0805
10uF | C53 | C1206
10uF | C55 | C0805
12.7K | R50 | 0402
12MHz | X1 | WE-XTAL_CFPX-180
15K 1% | R2 R33 | 0402
20K | R41 | 0402
22uF | C22 | C0805
22uF - 10V | C40 C41 C47 C48 | C1206
22uF 25V | C39 C46 | C1206
33K | R48 | 0402
33pF | C38 C45 | 0402
40.2K | R42 R49 | 0402
100K | R27 R32 R44 R51 | 0402
100K 1% | R11 | 0402
100nF | C1 | C0805
100nF | C3 C4 C5 | C0402
100nF | C9 | 0402
100nF | C10 | C0402
100nF | C11 | C1206
100nF | C12 C20 C21 C32 | C0402
100nF | C36 C37 C42 C43 C44 | 0402
100nF | C50 | C0402
100nF | C54 | C1206
100nF | C56 | C0402
100uF | C51 C52 | 100UF-16V
100uF 16V | C8 C35 | 100UF-16V
470K | R28 | 0402
470R | R8 R9 | 0402
499K | R38 R45 | 0402
629722000214 | USBC | 629722000214
685119136923 | HDMI2 | 685119136923
AO4407A | T5 | SO8
AP3441SHE-7B | IC5 | SON50P201X201X56-9T90X170N
AP22653W6 | IC2 IC7 | SOT23-6
BSS138 | T1 T2 T3 T4 T6 T7 T8 | SOT23
CRYSTAL | X2 | OSCCC500X320X130
DNI | R7 | 0402
FH12-22S-0.5SVA | DISP0 | FH12-22S-0.5SH
Green | LED1 LED3 | CHIPLED_0805
L | L1 | SRR5228A
M.2 | PCIE | PCIE_M.2
M2 x 1mm | 2230 2242 2260 2280 | WA-SMSI_9774010243
MMBT3906 | Q1 Q2 | SOT23
MP2315GJ-Z | IC3 | SOT65P280X110-8N
MP2315S | IC8 | SOT65P280X110-8N
NC | R15 R20 R25 R26 R29 R37 | 0402
RT9742GGJ | IC1 | SOT23-5
RT9742NGV | IC4 | SOT23
SS54B | D24 | SMB
TP | 3VDC 3VFB 5VDC 5VFB GND GND-3 GND-5 SW SW3 TP-5VHD TP-5VP TP-GREF TP-HUB TP-LED TP-LX TP-M2CLK TP-M2FB TP-VBUS TP-VM2 TP-VSD TP_5VP TP_5VP1 | TP
TPD4EUSB30 | D1 D2 D3 D4 D7 D8 D9 D13 D14 D15 D16 | USON

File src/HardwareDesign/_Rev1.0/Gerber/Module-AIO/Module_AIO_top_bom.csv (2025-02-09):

Comment | Designator | Footprint | LCSC Part #
 | C48 C74 | C0402
 | R49 R53 R54 | TC33X
0R | JP-3V3-1 JP-3V3-2 JP-EXT-1 JP-EXT-2 | 0603
0R | R9 R15 R24 R42 R43 R44 R45 R46 R47 R48 | 0402
0R | R51 R52 | 0603
1.2M 0.1% | R58 | 0402
1K | R10 R11 R25 R26 R27 R28 R29 R30 R31 R32 R33 R34 R35 R36 R37 R38 R40 R41 | 0402
1M | R68 | 0402
1uF | C15 C50 C52 C54 C56 C58 C60 C62 C64 C66 C68 C72 C122 C124 | C0402
2.2K 1% | R12 | 0402
3.2K 1% | R89 R93 R97 R101 | 0402
4.7K | R17 | 0402
4.7nF | C92 | C0402
4.7nF | C115 | 0402
4.7uF | C85 | C0402
5.1K | R61 R62 | 0402
10K | R16 R63 R64 R72 R75 R77 | 0402
10K 0.1% | R67 R71 R73 R76 R87 R88 R91 R92 R95 R96 R99 R100 R103 R104 R107 R108 R111 R112 R115 R116 | 0402
10R | R1 R2 R3 R4 R5 R6 R7 R8 | 0402
10nF | C91 C103 C106 C107 | C0402
10pF | C100 C101 | C0402
10uF | C47 C70 | C0402
10uF | C78 | 0805
10uF | C90 | C0402
10uF | C102 C104 | C0805
10uF | C110 | C0402
12nF | C139 C142 C145 C148 | C0402
15pF | C19 C20 | C0402
20K | R55 R56 | TC33X
20nF | C127 C130 C133 C136 | C0402
22uF | C93 C94 C95 C96 C97 C98 C108 C109 | C0805
27R | R13 R39 | 0402
68R 1% | R90 R94 R98 R102 | 0402
75K 0.1% | R60 | 0402
86K 1% | R105 R109 R113 R117 | 0402
90K 0.1% | R74 | 0402
100K 0.1% | R69 R70 | 0402
100R | R14 | 1206
100R | R50 | 0402
100nF | C1 C2 C3 C4 C5 C6 C7 C8 C9 C10 C11 C12 C13 C14 C16 C17 C18 C22 C25 C28 C29 C30 C31 C32 C33 C34 C35 C36 C37 C38 C39 C40 C45 C46 C49 C51 C53 C55 C57 C59 C61 C63 C65 C67 C69 C71 C73 C75 C76 C77 | C0402
100nF | C79 | 0402
100nF | C80 C81 C82 C83 C84 C86 C87 C88 C89 C111 C112 C113 C114 C116 C120 C121 C123 C125 C126 C128 C129 C131 C134 C137 C140 C143 C146 C149 | C0402
100uF 16V | C26 C27 | 100UF-16V
102K 0.1% | R57 | 0402
110R 1% | R106 R110 R114 R118 | 0402
137K 0.1% | R59 | 0402
200R | R20 R21 R22 R23 | 0402
220nF | C99 C105 | C0402
270pF | C23 C24 C42 C43 | C0402
680pF | C41 C44 | C0402
950K 0.1% | R19 | 0402
AD8605 | IC11 IC13 IC23 | SOT23-5
ADA4254ACPZ | IC7 IC9 | QFN50P500X500X75-29T314N
ADS9234RIRHBR | IC10 | VQFN32-5X5
B3U-1000P-B | RESET USB_BOOT | SWITCH-OMRON_B3U-1000P
CRA034RF100RP05Z | R86 | YC164-JR-0733RL
DAC8568 | IC22 | TSSOP16
DG409 | IC6 IC8 | TSSOP2
DNI | R18 | 0402
IRLML5203 | T2 | MICRO3
K5A1200015304P | X2 | OSCCC500X320X130
LM4040BXX | REF1 | SOT23
MCP1525T-I/TT | IC12 | SOT23
MCP6001AIDBVRG | IC3 | SOT23-5
MIC5504-3.3YM5-TR | IC1 | SOT23-5
OPA192 | IC24 IC25 IC26 IC27 | SOT23-5
OPA197 | IC28 IC29 IC30 IC31 | SOT23-5
RP2040 | IC2 | QFN40P700X700X100-57T510
SP0503BAHTG-ES | ESD1 | SOT143
SRR5228A-4R7Y | L3 L4 | SRR5228A
SS12 | D1 D3 D4 | SMA
TP | 12VN 12VP AVDD BUF CLR CS0 CS1 CS2 CS3 DAC0 DAC1 DAC2 DAC3 DAC4 DAC5 DAC6 DAC7 DVDD IOVDD LDAC MISO MOSI REFBY2 REFOUT SCK TP_3V3 TP_GND VBUS VOCMA VREF1 VREF_DAC | TP
TPS7A39 | IC15 | WSON10-3X3
TPS65131 | IC14 | VQFN24-4X4-THERMAL2.5X2.5
USB-TYPE-C-018 | USBC | 629722000214
W25Q128JVPIQ | IC4 | SON127P600X500X75-8N

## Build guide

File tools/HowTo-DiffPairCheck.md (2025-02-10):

# DiffPairCheck.exe - Differential Pair Length Checker

DiffPairCheck.exe is a standalone Windows application designed to verify the length matching of differential pairs in high‑speed designs. It processes signal reports exported from Eagle (using the Eagle ULP "length") and checks that the lengths of paired signals meet the required tolerances for a given interface. The application groups signals based on strict naming conventions and allows users to assign interfaces to each pair, run detailed checks, and export a Markdown report of the results.

## Naming Conventions
DiffPairCheck.exe relies on a strict naming convention to accurately group differential pairs. The signal names must follow the format outlined in the [Key Design Rules for Differential Pairs for Interfaces](https://github.com/DvidMakesThings/HW_10-In-Rack_DAQ/blob/master/docs/Manuals/Key%20Design%20Rules%20for%20Differential%20pairs%20for%20Interfaces.pdf):

- **Format:**  
  **InterfaceName + _DiffPairName + ( _N or _P )**
  
  For example:
  - `ETH1_TX4_N` / `ETH1_TX4_P`  
    → These signals belong to the Ethernet interface labeled **ETH1** and represent a differential pair (TX4).
  - `ETH0_TX4_N` / `ETH0_TX4_P`  
    → These signals belong to a different Ethernet interface **ETH0** and are treated as a separate group.

Following this naming convention ensures that signals from different connectors or interfaces (such as HDMI0 vs. HDMI1, ETH0 vs. ETH1, etc.) are grouped correctly and checked only against others in the same group.

## Preparing Your Signal Report

Before using DiffPairCheck.exe, you must export the signal length list from your Eagle design:
1. **Export with Eagle ULP "length":**  
   Use the Eagle ULP named `length` to generate a text file containing the signal names and their lengths in millimeters.
2. **Save the File:**  
   Save the exported text file to a location of your choice.
3. **Import into DiffPairCheck.exe:**  
   When you launch DiffPairCheck.exe, use the **Load Signal File** button to browse and select your exported text file.

## How to Use DiffPairCheck.exe

1. **Launch the Application:**  
   Double-click on `DiffPairCheck.exe` to start the program.

2. **Load a Signal File:**  
   - Click the **Load Signal File** button in the top-left section.
   - Navigate to the location of your exported Eagle signal report (the text file) and select it.
   - The filename will be displayed, confirming that the file has been loaded successfully.

3. **Review and Assign Interfaces:**  
   - The left pane lists the detected differential pairs. Each row shows the two channels (those ending with `_N` and `_P`) and includes a dropdown menu pre‑assigned with a recommended interface.
   - If necessary, adjust the interface assignment for any pair using the dropdown.

4. **Run the Check:**  
   - Click the **Run Check** button (displayed as a dark green button that becomes even darker on hover) located in the center of the button frame.
   - The application will:
     - **Pair Check:** Verify that the length difference between the two channels of each pair is within the specified pair tolerance.
     - **Inter‑Pair Check:** For groups with multiple pairs (e.g., all signals from a specific connector), it determines the longest and shortest average trace lengths and checks that their difference does not exceed the inter‑pair tolerance.
     - **HDMI 1.4 Extra Check:** Ensure that the TMDSCK (clock) pair’s average length is shorter than those of the data lane pairs.
   - The results are displayed in a table on the right pane, showing columns for Group, Pair, Diff (mm), Tolerance (mm), and Status (with PASS shown in green and FAIL in red).

5. **Save the Report:**  
   - Click the **Save Report** button (located to the right of the Run Check button).
   - In the save dialog, choose a destination and filename for your Markdown report.
   - The saved report will include a header with the input filename, timestamp, overall status (colored green for PASS or red for FAIL), and a neatly formatted table of results.

## Example Report Format

Below is an example of the Markdown report generated by DiffPairCheck.exe:

| **Group** | **Pair** | **Diff (mm)** | **Tolerance (mm)** | **Status** |
| --- | --- | --- | --- | --- |
| **Ethernet 1000BASE-T (ETH1)**| ----- | | | |
| | ETH1_TX4_N / ETH1_TX4_P | 0.471 | ±0.127 | <span style="color:red">FAIL</span> |
| | ETH1_TX3_N / ETH1_TX3_P | 0.528 | ±0.127 | <span style="color:red">FAIL</span> |
| | ETH1_TX2_N / ETH1_TX2_P | 0.581 | ±0.127 | <span style="color:red">FAIL</span> |
| | ETH1_TX1_N / ETH1_TX1_P | 0.607 | ±0.127 | <span style="color:red">FAIL</span> |
| | **Inter‑Pair** | 12.271 | ±0.254 | <span style="color:red">FAIL</span> |
| **HDMI 1.4 (HDMI0)** | ----- | | | |
| | HDMI0_TDMSCK_N / HDMI0_TDMSCK_P | 0.562 | ±0.127 | <span style="color:red">FAIL</span> |
| | HDMI0_TDMS0_N / HDMI0_TDMS0_P | 0.485 | ±0.127 | <span style="color:red">FAIL</span> |
| | HDMI0_TDMS1_N / HDMI0_TDMS1_P | 0.408 | ±0.127 | <span style="color:red">FAIL</span> |
| | HDMI0_TDMS2_N / HDMI0_TDMS2_P | 0.508 | ±0.127 | <span style="color:red">FAIL</span> |
| | **Inter‑Pair** | 9.342 | ±0.508 | <span style="color:red">FAIL</span> |
| | HDMI0_TDMSCK_N / HDMI0_TDMSCK_P (TMDSCK) | 43.453 | | <span style="color:green">PASS</span> |

The report header also includes:
- **Input File:** Name of the loaded signal report
- **Date/Time:** When the report was generated
- **Overall Status:** Displayed in large, colored text (green for PASS, red for FAIL)

## Troubleshooting

- **File Loading Issues:**  
  Ensure your signal report is exported using the Eagle ULP "length" in the expected tab‑separated format with at least two columns (signal name and length in mm).

- **Incomplete Pairs:**  
  If you see “Incomplete pair” messages, verify that every differential pair has both an `_N` and a `_P` signal, and that the naming follows the correct convention.

- **Interface Assignment:**  
  Adjust the pre‑assigned interfaces using the dropdown menus if the default recommendations do not match your design.

## License

This project is licensed under the **GPL-3.0 License**. See the [LICENSE](LICENSE) file for details.

## Contact

For questions or feedback:
- **Email:** [s.dvid@hotmail.com](mailto:s.dvid@hotmail.com)
- **GitHub:** [DvidMakesThings](https://github.com/DvidMakesThings)

> **Source Code:**  
> [https://github.com/DvidMakesThings/WINAPP_Windows-Apps/tree/master/diffpaircheck](https://github.com/DvidMakesThings/WINAPP_Windows-Apps/tree/master/diffpaircheck)

Enjoy using DiffPairCheck.exe to ensure your high‑speed designs meet the necessary differential pair matching requirements!

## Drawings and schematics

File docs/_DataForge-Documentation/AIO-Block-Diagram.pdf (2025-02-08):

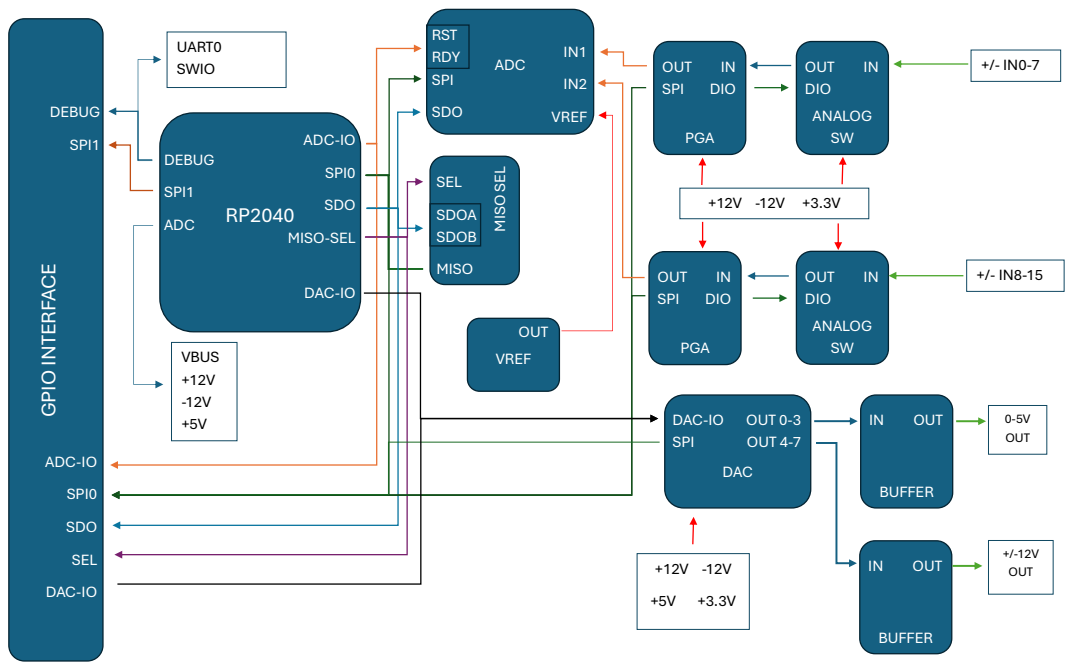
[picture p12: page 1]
ADC; SPI0; SDO; MISO; -SEL; DAC; DEBUG; SPI1; OUT SPI; IN DIO; VBUS +12V -12V; UART0 SWIO; GPIO INTERFACE; SPI; SEL; RST RD; Y SPI; VREF; SDOA SDOB; ANALOG SW; OUT DIO; OUT; OUT 0; OUT 4; BUFFER; -5V OUT

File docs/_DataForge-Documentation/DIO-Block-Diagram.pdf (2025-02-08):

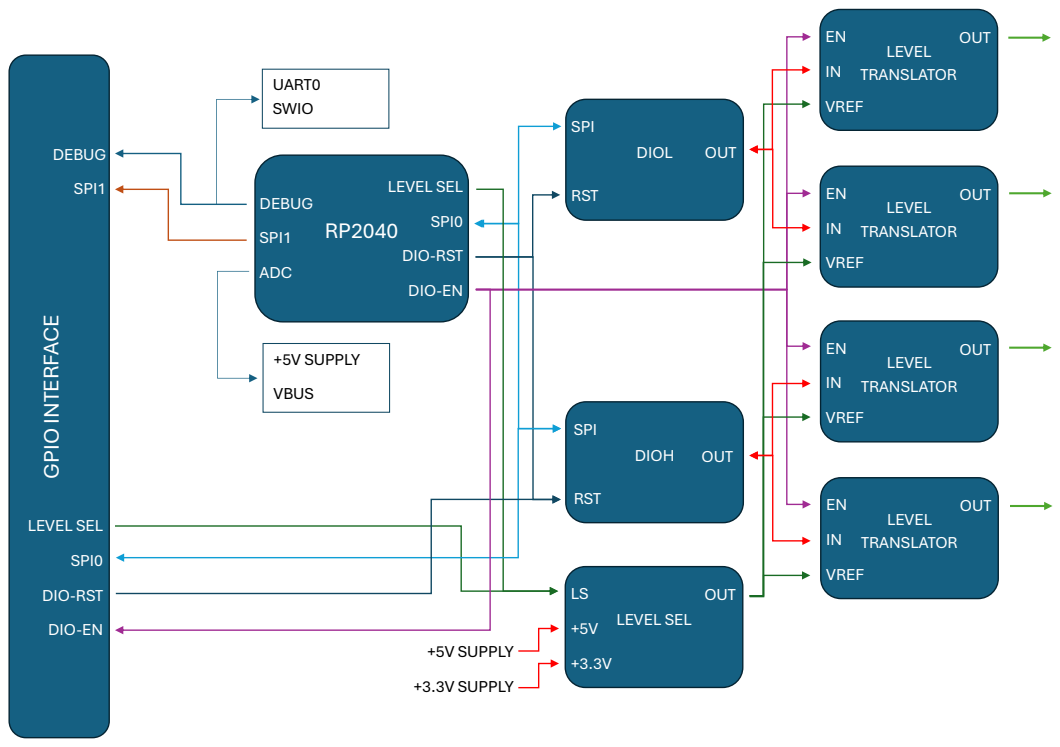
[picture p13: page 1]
LEVEL SEL; SPI0; DIO; -RST; DEBUG; SPI1; ADC; DIOL; SPI; RST; OUT; DIOH; LEVEL TRANSLATOR; VREF; +5V SUPPLY; +3.3V SUPPLY; VBUS; UART0 SWIO; GPIO INTERFACE

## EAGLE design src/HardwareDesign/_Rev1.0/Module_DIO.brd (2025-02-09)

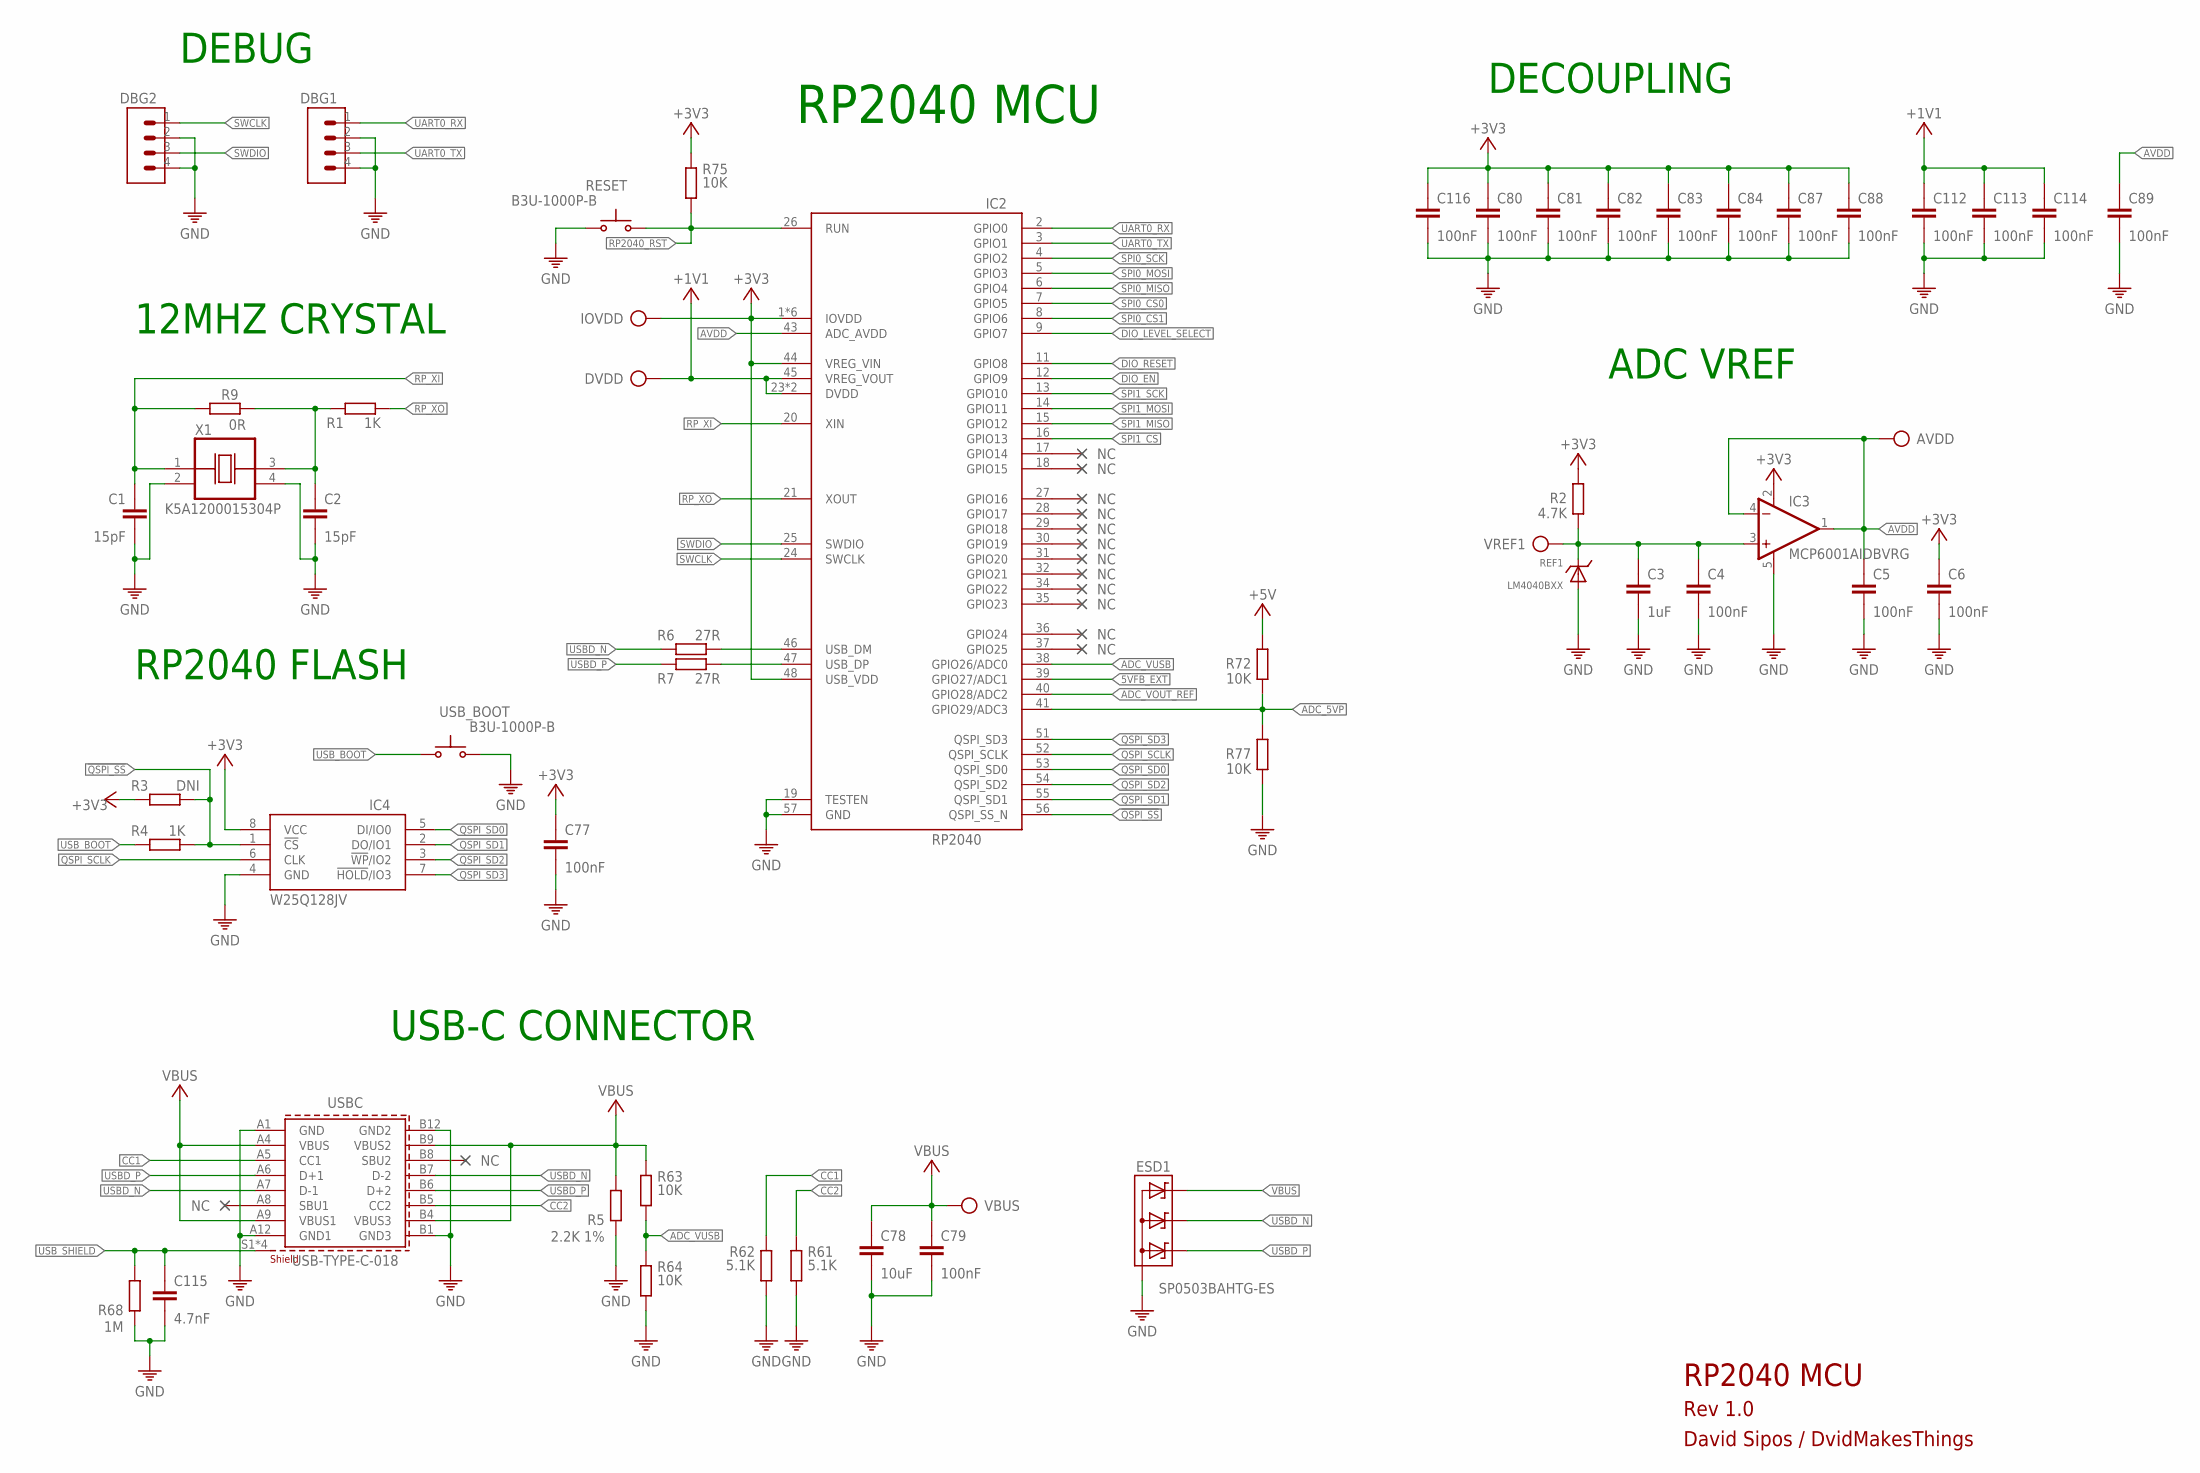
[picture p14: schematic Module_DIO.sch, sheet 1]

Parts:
AVDD: TP
C1, C2: 15pF; C0402
C3: 1uF; C0402
C4, C5, C6, C77, C80, C81, C82, C83, C84, C87, C88, C89, C112, C113, C114, C116: 100nF; C0402
C78: 10uF; 0805
C79: 100nF; 0402
C115: 4.7nF; 0402
DBG1, DBG2: CON-1X4; 1X4
DVDD: TP
ESD1: SP0503BAHTG-ES; SOT143
IC2: RP2040; QFN40P700X700X100-57T510
IC3: MCP6001AIDBVRG; SOT23-5
IC4: W25Q128JVPIQ; SON127P600X500X75-8N
IOVDD: TP
R1, R4: 1K; 0402
R2: 4.7K; 0402
R3: DNI; 0402
R5: 2.2K 1%; 0402
R6, R7: 27R; 0402
R9: 0R; 0402
R61, R62: 5.1K; 0402
R63, R64, R72, R75, R77: 10K; 0402
R68: 1M; 0402
REF1: LM4040BXX; SOT23
RESET: B3U-1000P-B; SWITCH-OMRON_B3U-1000P
USBC: USB-TYPE-C-018; 629722000214
USB_BOOT: B3U-1000P-B; SWITCH-OMRON_B3U-1000P
VBUS: TP
VREF1: TP
X1: K5A1200015304P; OSCCC500X320X130

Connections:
5VFB_EXT: IC2.39 (GPIO27/ADC1)
!QSPI_SS: IC2.56 (QSPI_SS_N), IC4.1 (!CS), R3.1, R4.2
+1V1: C112.1, C113.1, C114.1, DVDD.TP, IC2.23 (DVDD), IC2.45 (VREG_VOUT), IC2.50 (DVDD)
+3V3: C6.1, C77.1, C80.1, C81.1, C82.1, C83.1, C84.1, C87.1, C88.1, C116.1, IC2.1 (IOVDD), IC2.10 (IOVDD), IC2.22 (IOVDD), IC2.33 (IOVDD), IC2.42 (IOVDD), IC2.44 (VREG_VIN), IC2.48 (USB_VDD), IC2.49 (IOVDD), IC3.2 (V+), IC4.8 (VCC), IOVDD.TP, R2.2, R3.2, R75.1; also elsewhere on the board
+5V: R72.2; also elsewhere on the board
ADC_5VP: IC2.41 (GPIO29/ADC3), R72.1, R77.2
ADC_VOUT_REF: IC2.40 (GPIO28/ADC2); also elsewhere on the board
ADC_VUSB: IC2.38 (GPIO26/ADC0), R63.2, R64.1
AVDD: AVDD.TP, C5.1, C89.1, IC2.43 (ADC_AVDD), IC3.1 (OUT), IC3.4 (-IN)
CC1: R62.1, USBC.A5 (CC1)
CC2: R61.1, USBC.B5 (CC2)
DIO_EN: IC2.12 (GPIO9); also elsewhere on the board
DIO_LEVEL_SELECT: IC2.9 (GPIO7); also elsewhere on the board
DIO_RESET: IC2.11 (GPIO8); also elsewhere on the board
GND: C1.2, C2.2, C3.2, C4.2, C5.2, C6.2, C77.2, C78.2, C79.2, C80.2, C81.2, C82.2, C83.2, C84.2, C87.2, C88.2, C89.2, C112.2, C113.2, C114.2, C115.2, C116.2, DBG1.2, DBG1.4, DBG2.2, DBG2.4, ESD1.1 (A), IC2.19 (TESTEN), IC2.57 (GND), IC3.5 (V-), IC4.4 (GND), R5.2, R61.2, R62.2, R64.2, R68.2, R77.1, REF1.2 (A), REF1.3 (A), RESET.2 (S), USBC.A1 (GND), USBC.A12 (GND1), USBC.B1 (GND3), USBC.B12 (GND2), USB_BOOT.2 (S), X1.2 (VSS), X1.4 (VDD); also elsewhere on the board
unnamed: C2.1, R1.1, R9.2, X1.3 (OUT)
QSPI_SCLK: IC2.52 (QSPI_SCLK), IC4.6 (CLK)
QSPI_SD0: IC2.53 (QSPI_SD0), IC4.5 (DI/IO0)
QSPI_SD1: IC2.55 (QSPI_SD1), IC4.2 (DO/IO1)
QSPI_SD2: IC2.54 (QSPI_SD2), IC4.3 (!WP!/IO2)
QSPI_SD3: IC2.51 (QSPI_SD3), IC4.7 (!HOLD!/IO3)
RP2040_RST: IC2.26 (RUN), R75.2, RESET.1; also elsewhere on the board
RP_USBD_N: IC2.46 (USB_DM), R6.2
RP_USBD_P: IC2.47 (USB_DP), R7.2
RP_XI: C1.1, IC2.20 (XIN), R9.1, X1.1 (CON)
RP_XO: IC2.21 (XOUT), R1.2
SPI0_CS0: IC2.7 (GPIO5); also elsewhere on the board
SPI0_CS1: IC2.8 (GPIO6); also elsewhere on the board
SPI0_MISO: IC2.6 (GPIO4); also elsewhere on the board
SPI0_MOSI: IC2.5 (GPIO3); also elsewhere on the board
SPI0_SCK: IC2.4 (GPIO2); also elsewhere on the board
SPI1_CS: IC2.16 (GPIO13); also elsewhere on the board
SPI1_MISO: IC2.15 (GPIO12); also elsewhere on the board
SPI1_MOSI: IC2.14 (GPIO11); also elsewhere on the board
SPI1_SCK: IC2.13 (GPIO10); also elsewhere on the board
SWCLK: DBG2.1, IC2.24 (SWCLK); also elsewhere on the board
SWDIO: DBG2.3, IC2.25 (SWDIO); also elsewhere on the board
UART0_RX: DBG1.1, IC2.2 (GPIO0); also elsewhere on the board
UART0_TX: DBG1.3, IC2.3 (GPIO1); also elsewhere on the board
USBD_N: ESD1.3 (C2), R6.1, USBC.A7 (D-1), USBC.B7 (D-2)
USBD_P: ESD1.2 (C1), R7.1, USBC.A6 (D+1), USBC.B6 (D+2)
USB_BOOT: R4.1, USB_BOOT.1
USB_SHIELD: C115.1, R68.1, USBC.S1 (SHIELD), USBC.S2 (SHIELD), USBC.S3 (SHIELD), USBC.S4 (SHIELD)
VBUS: C78.1, C79.1, ESD1.4 (C3), R5.1, R63.1, USBC.A4 (VBUS), USBC.A9 (VBUS1), USBC.B4 (VBUS3), USBC.B9 (VBUS2), VBUS.TP; also elsewhere on the board
VREF: C3.1, C4.1, IC3.3 (+IN), R2.1, REF1.1 (C), VREF1.TP

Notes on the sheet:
USB-C CONNECTOR
DECOUPLING
12MHZ CRYSTAL
RP2040 MCU
RP2040 FLASH
ADC VREF
DEBUG
Rev 1.0
David Sipos / DvidMakesThings

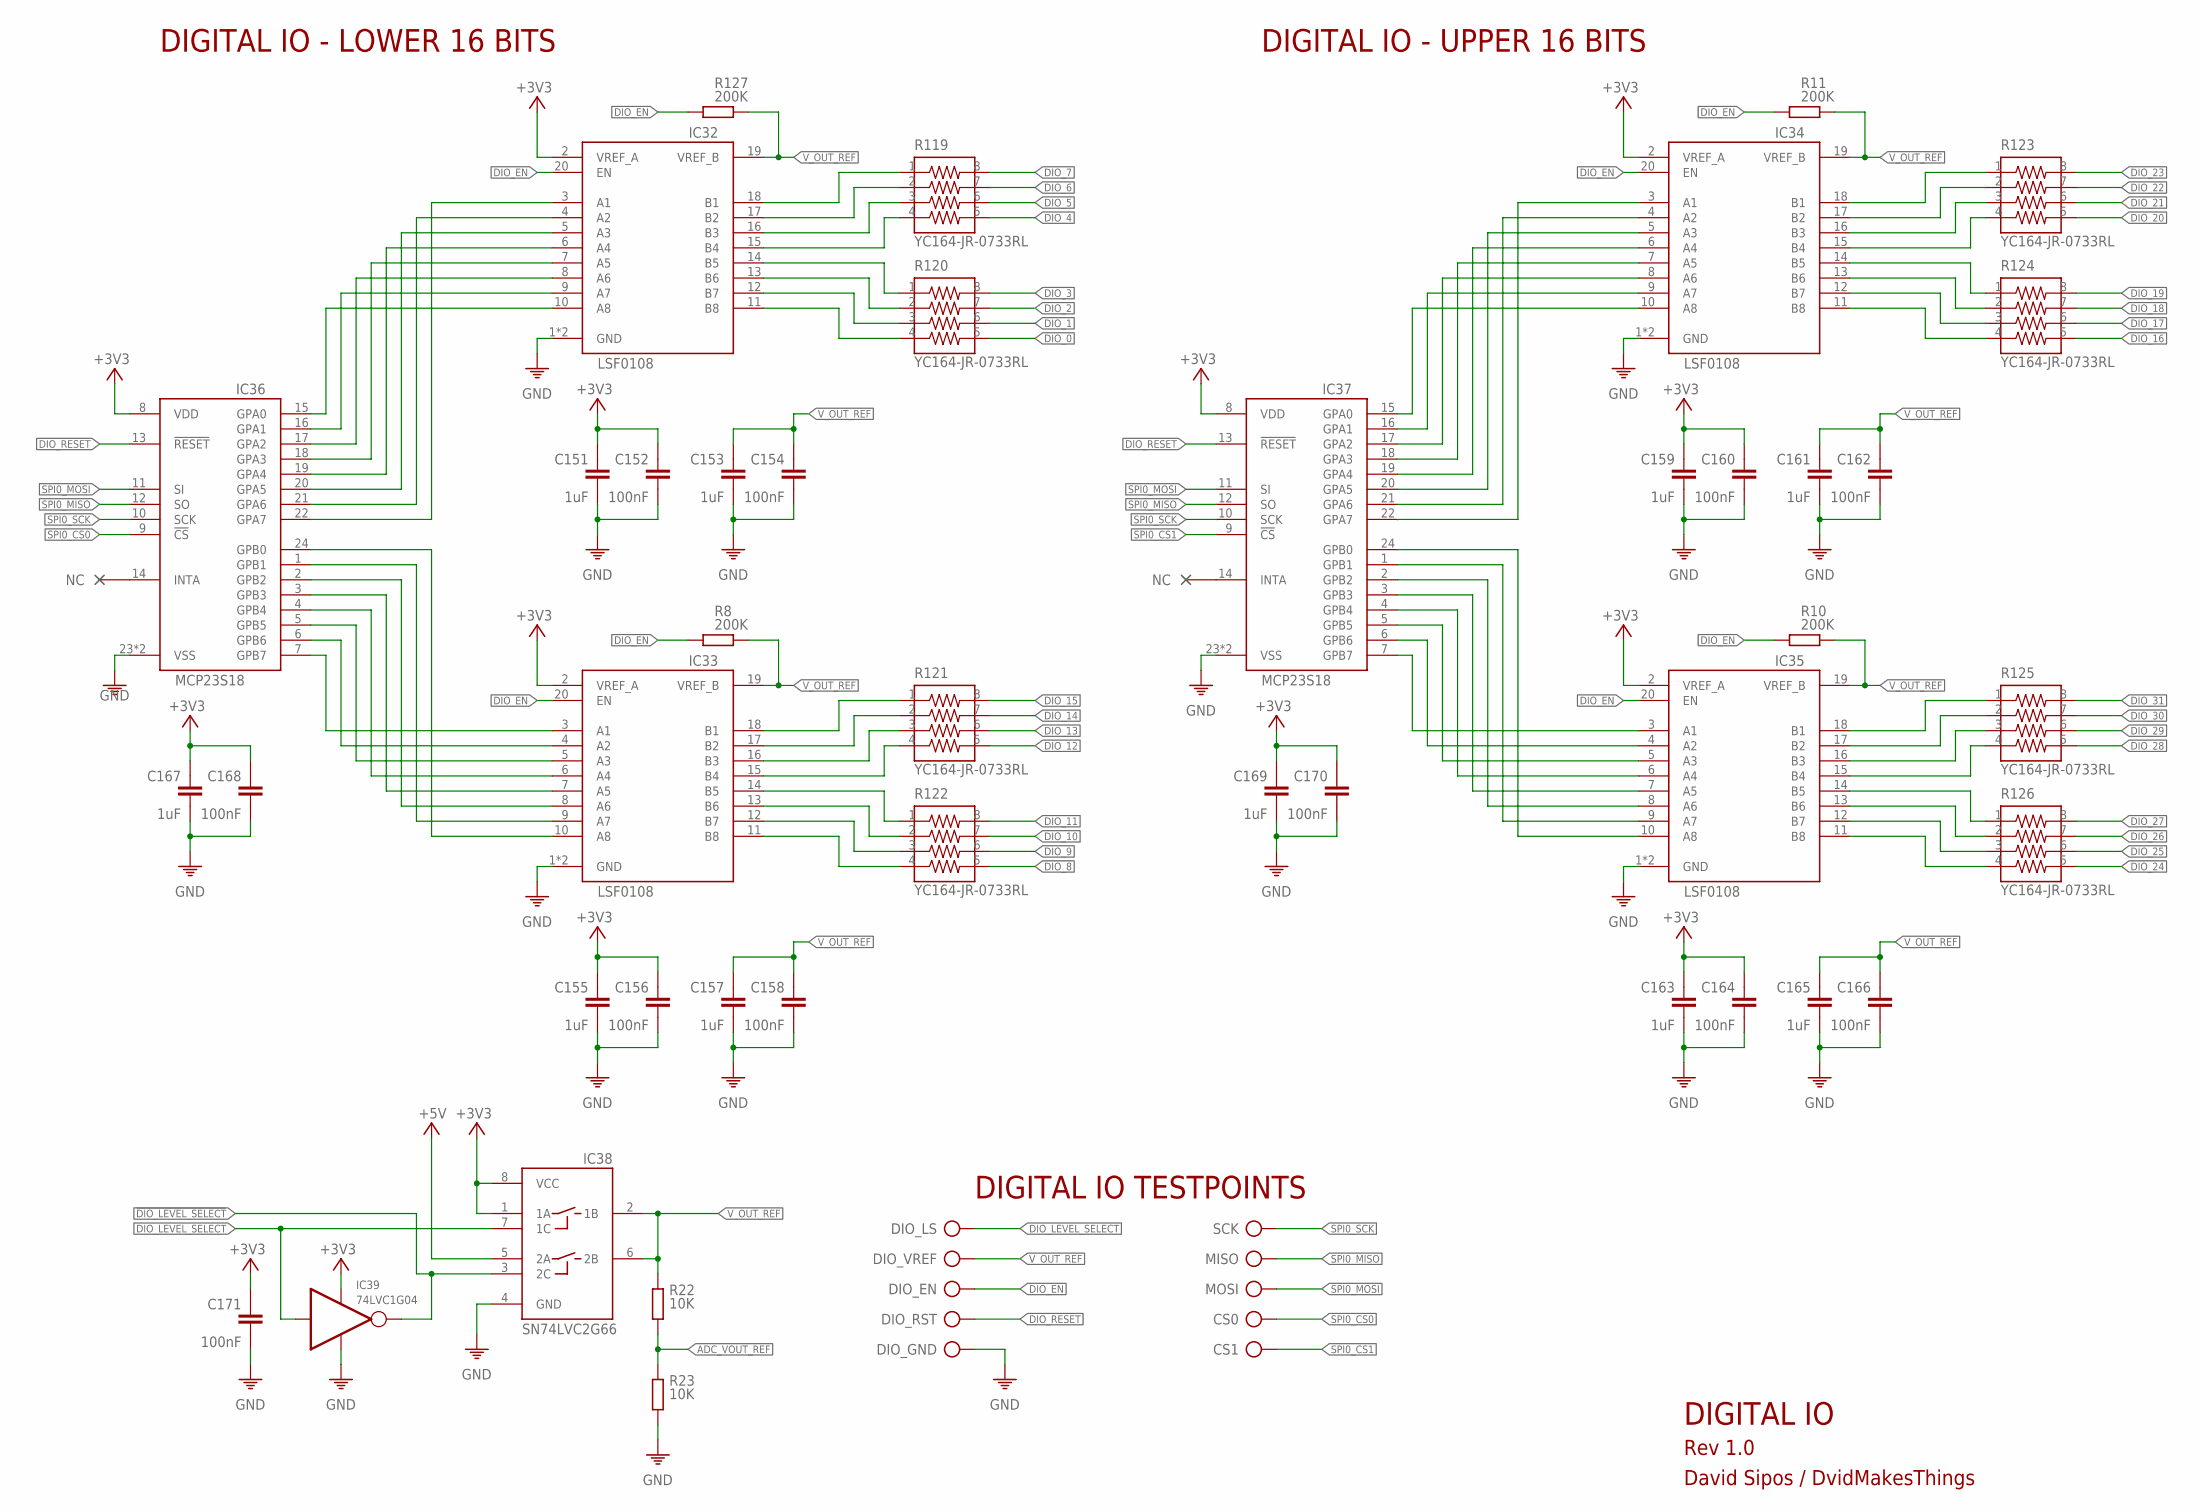
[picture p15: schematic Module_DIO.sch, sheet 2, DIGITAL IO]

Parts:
C151, C153, C155, C157, C159, C161, C163, C165, C167, C169: 1uF; C0402
C152, C154, C156, C158, C160, C162, C164, C166, C168, C170: 100nF; C0402
C171: 100nF; C0603
CS0, CS1: TP
DIO_EN: TP
DIO_GND: TP
DIO_LS: TP
DIO_RST: TP
DIO_VREF: TP
IC32, IC33, IC34, IC35: LSF0108; VQFN20
IC36, IC37: MCP23S18; QFN50P400X400X100-25T265
IC38: SN74LVC2G66; SOP50P310X90-8N
IC39: 74LVC1G04; SOT95P280X145-5N
MISO: TP
MOSI: TP
R8, R10, R11, R127: 200K; 0402
R22, R23: 10K; 0402
R119, R120, R121, R122, R123, R124, R125, R126: YC164-JR-0733RL
SCK: TP

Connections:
!DIO_LEVEL_SELECT: IC38.3 (2C), IC39.4 (OUT)
+3V3: C151.1, C152.1, C155.1, C156.1, C159.1, C160.1, C163.1, C164.1, C167.1, C168.1, C169.1, C170.1, C171.1, IC32.2 (VREF_A), IC33.2 (VREF_A), IC34.2 (VREF_A), IC35.2 (VREF_A), IC36.8 (VDD), IC37.8 (VDD), IC38.1 (1A), IC38.8 (VCC), IC39.5 (V+); also elsewhere on the board
+5V: IC38.5 (2A); also elsewhere on the board
ADC_VOUT_REF: R22.2, R23.1; also elsewhere on the board
DIO_0: R120.5; also elsewhere on the board
DIO_1: R120.6; also elsewhere on the board
DIO_2: R120.7; also elsewhere on the board
DIO_3: R120.8; also elsewhere on the board
DIO_4: R119.5; also elsewhere on the board
DIO_5: R119.6; also elsewhere on the board
DIO_6: R119.7; also elsewhere on the board
DIO_7: R119.8; also elsewhere on the board
DIO_8: R122.5; also elsewhere on the board
DIO_9: R122.6; also elsewhere on the board
DIO_10: R122.7; also elsewhere on the board
DIO_11: R122.8; also elsewhere on the board
DIO_12: R121.5; also elsewhere on the board
DIO_13: R121.6; also elsewhere on the board
DIO_14: R121.7; also elsewhere on the board
DIO_15: R121.8; also elsewhere on the board
DIO_16: R124.5; also elsewhere on the board
DIO_17: R124.6; also elsewhere on the board
DIO_18: R124.7; also elsewhere on the board
DIO_19: R124.8; also elsewhere on the board
DIO_20: R123.5; also elsewhere on the board
DIO_21: R123.6; also elsewhere on the board
DIO_22: R123.7; also elsewhere on the board
DIO_23: R123.8; also elsewhere on the board
DIO_24: R126.5; also elsewhere on the board
DIO_25: R126.6; also elsewhere on the board
DIO_26: R126.7; also elsewhere on the board
DIO_27: R126.8; also elsewhere on the board
DIO_28: R125.5; also elsewhere on the board
DIO_29: R125.6; also elsewhere on the board
DIO_30: R125.7; also elsewhere on the board
DIO_31: R125.8; also elsewhere on the board
DIO_EN: DIO_EN.TP, IC32.20 (EN), IC33.20 (EN), IC34.20 (EN), IC35.20 (EN), R8.2, R10.2, R11.2, R127.2; also elsewhere on the board
DIO_LEVEL_SELECT: DIO_LS.TP, IC38.7 (1C), IC39.2 (IN); also elsewhere on the board
DIO_RESET: DIO_RST.TP, IC36.13 (!RESET), IC37.13 (!RESET); also elsewhere on the board
GND: C151.2, C152.2, C153.2, C154.2, C155.2, C156.2, C157.2, C158.2, C159.2, C160.2, C161.2, C162.2, C163.2, C164.2, C165.2, C166.2, C167.2, C168.2, C169.2, C170.2, C171.2, DIO_GND.TP, IC32.1 (GND), IC32.PAD (GND), IC33.1 (GND), IC33.PAD (GND), IC34.1 (GND), IC34.PAD (GND), IC35.1 (GND), IC35.PAD (GND), IC36.23 (VSS), IC36.25 (VSS), IC37.23 (VSS), IC37.25 (VSS), IC38.4 (GND), IC39.3 (V-), R23.2; also elsewhere on the board
unnamed: IC33.9 (A7), IC36.1 (GPB1)
unnamed: IC32.10 (A8), IC36.15 (GPA0)
unnamed: IC32.9 (A7), IC36.16 (GPA1)
unnamed: IC32.8 (A6), IC36.17 (GPA2)
unnamed: IC32.7 (A5), IC36.18 (GPA3)
unnamed: IC32.6 (A4), IC36.19 (GPA4)
unnamed: IC32.5 (A3), IC36.20 (GPA5)
unnamed: IC32.4 (A2), IC36.21 (GPA6)
unnamed: IC32.3 (A1), IC36.22 (GPA7)
unnamed: IC32.18 (B1), R119.1
unnamed: IC32.17 (B2), R119.2
unnamed: IC32.16 (B3), R119.3
unnamed: IC32.15 (B4), R119.4
unnamed: IC32.14 (B5), R120.1
unnamed: IC32.13 (B6), R120.2
unnamed: IC32.12 (B7), R120.3
unnamed: IC32.11 (B8), R120.4
unnamed: IC33.10 (A8), IC36.24 (GPB0)
unnamed: IC33.8 (A6), IC36.2 (GPB2)
unnamed: IC33.7 (A5), IC36.3 (GPB3)
unnamed: IC33.6 (A4), IC36.4 (GPB4)
unnamed: IC33.5 (A3), IC36.5 (GPB5)
unnamed: IC33.4 (A2), IC36.6 (GPB6)
unnamed: IC33.3 (A1), IC36.7 (GPB7)
unnamed: IC33.18 (B1), R121.1
unnamed: IC33.17 (B2), R121.2
unnamed: IC33.16 (B3), R121.3
unnamed: IC33.15 (B4), R121.4
unnamed: IC33.14 (B5), R122.1
unnamed: IC33.13 (B6), R122.2
unnamed: IC33.12 (B7), R122.3
unnamed: IC33.11 (B8), R122.4
unnamed: IC34.10 (A8), IC37.15 (GPA0)
unnamed: IC34.9 (A7), IC37.16 (GPA1)
unnamed: IC34.8 (A6), IC37.17 (GPA2)
unnamed: IC34.7 (A5), IC37.18 (GPA3)
unnamed: IC34.6 (A4), IC37.19 (GPA4)
unnamed: IC34.5 (A3), IC37.20 (GPA5)
unnamed: IC34.4 (A2), IC37.21 (GPA6)
unnamed: IC34.3 (A1), IC37.22 (GPA7)
unnamed: IC34.18 (B1), R123.1
unnamed: IC34.17 (B2), R123.2
unnamed: IC34.16 (B3), R123.3
unnamed: IC34.15 (B4), R123.4
unnamed: IC34.14 (B5), R124.1
unnamed: IC34.13 (B6), R124.2
unnamed: IC34.12 (B7), R124.3
unnamed: IC34.11 (B8), R124.4
unnamed: IC35.8 (A6), IC37.2 (GPB2)
unnamed: IC35.7 (A5), IC37.3 (GPB3)
unnamed: IC35.6 (A4), IC37.4 (GPB4)
unnamed: IC35.5 (A3), IC37.5 (GPB5)
unnamed: IC35.4 (A2), IC37.6 (GPB6)
unnamed: IC35.3 (A1), IC37.7 (GPB7)
unnamed: IC35.9 (A7), IC37.1 (GPB1)
unnamed: IC35.10 (A8), IC37.24 (GPB0)
unnamed: IC35.18 (B1), R125.1
unnamed: IC35.17 (B2), R125.2
unnamed: IC35.16 (B3), R125.3
unnamed: IC35.15 (B4), R125.4
unnamed: IC35.14 (B5), R126.1
unnamed: IC35.13 (B6), R126.2
unnamed: IC35.12 (B7), R126.3
unnamed: IC35.11 (B8), R126.4
SPI0_CS0: CS0.TP, IC36.9 (!CS); also elsewhere on the board
SPI0_CS1: CS1.TP, IC37.9 (!CS); also elsewhere on the board
SPI0_MISO: IC36.12 (SO), IC37.12 (SO), MISO.TP; also elsewhere on the board
SPI0_MOSI: IC36.11 (SI), IC37.11 (SI), MOSI.TP; also elsewhere on the board
SPI0_SCK: IC36.10 (SCK), IC37.10 (SCK), SCK.TP; also elsewhere on the board
V_OUT_REF: C153.1, C154.1, C157.1, C158.1, C161.1, C162.1, C165.1, C166.1, DIO_VREF.TP, IC32.19 (VREF_B), IC33.19 (VREF_B), IC34.19 (VREF_B), IC35.19 (VREF_B), IC38.2 (1B), IC38.6 (2B), R8.1, R10.1, R11.1, R22.1, R127.1

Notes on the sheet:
DIGITAL IO - LOWER 16 BITS
DIGITAL IO - UPPER 16 BITS
DIGITAL IO TESTPOINTS
DIGITAL IO
Rev 1.0
David Sipos / DvidMakesThings

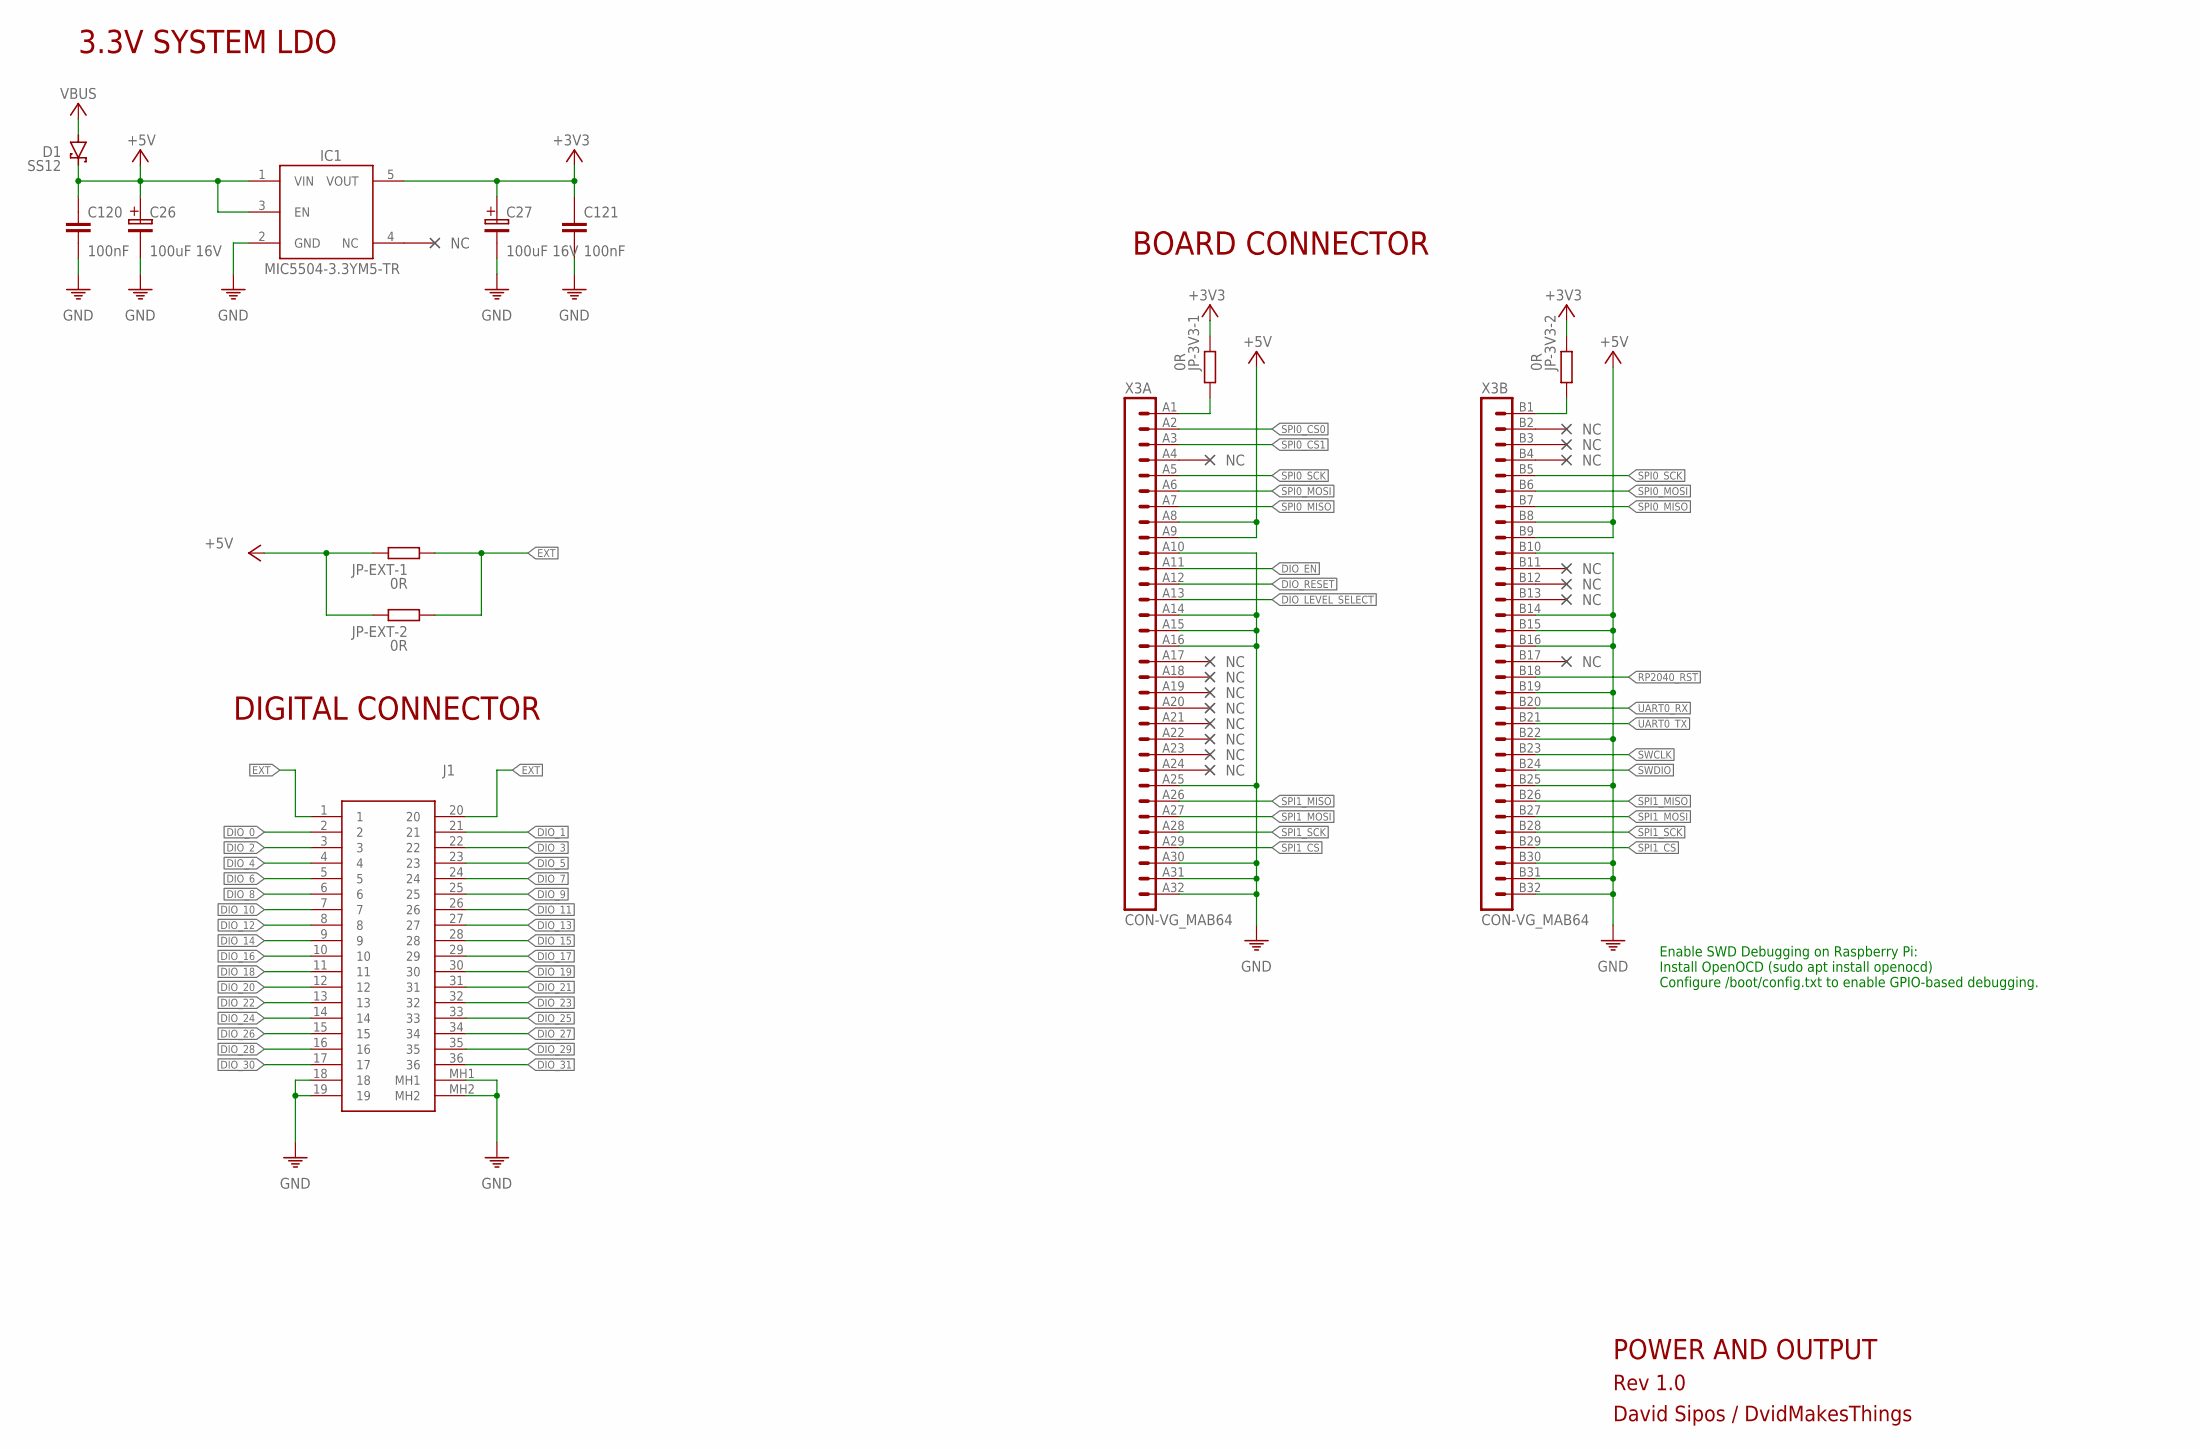
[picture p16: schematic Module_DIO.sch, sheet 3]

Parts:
C26, C27: 100uF 16V; 100UF-16V
C120, C121: 100nF; C0402
D1: SS12; SMA
IC1: MIC5504-3.3YM5-TR; SOT23-5
J1: N10236-52B3PC; MDB36
JP-3V3-1, JP-3V3-2: 0R; 0603
JP-EXT-1, JP-EXT-2: 0R; 0603
X3: CON-VG_MAB64

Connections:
+3V3: C27.1, C121.1, IC1.5 (VOUT), JP-3V3-1.1, JP-3V3-2.1; also elsewhere on the board
+5V: C26.1, C120.1, D1.C, IC1.1 (VIN), IC1.3 (EN), JP-EXT-1.1, JP-EXT-2.1, X3.A8 (8), X3.A9 (9), X3.B8 (8), X3.B9 (9); also elsewhere on the board
DIO_0: J1.2; also elsewhere on the board
DIO_1: J1.21; also elsewhere on the board
DIO_2: J1.3; also elsewhere on the board
DIO_3: J1.22; also elsewhere on the board
DIO_4: J1.4; also elsewhere on the board
DIO_5: J1.23; also elsewhere on the board
DIO_6: J1.5; also elsewhere on the board
DIO_7: J1.24; also elsewhere on the board
DIO_8: J1.6; also elsewhere on the board
DIO_9: J1.25; also elsewhere on the board
DIO_10: J1.7; also elsewhere on the board
DIO_11: J1.26; also elsewhere on the board
DIO_12: J1.8; also elsewhere on the board
DIO_13: J1.27; also elsewhere on the board
DIO_14: J1.9; also elsewhere on the board
DIO_15: J1.28; also elsewhere on the board
DIO_16: J1.10; also elsewhere on the board
DIO_17: J1.29; also elsewhere on the board
DIO_18: J1.11; also elsewhere on the board
DIO_19: J1.30; also elsewhere on the board
DIO_20: J1.12; also elsewhere on the board
DIO_21: J1.31; also elsewhere on the board
DIO_22: J1.13; also elsewhere on the board
DIO_23: J1.32; also elsewhere on the board
DIO_24: J1.14; also elsewhere on the board
DIO_25: J1.33; also elsewhere on the board
DIO_26: J1.15; also elsewhere on the board
DIO_27: J1.34; also elsewhere on the board
DIO_28: J1.16; also elsewhere on the board
DIO_29: J1.35; also elsewhere on the board
DIO_30: J1.17; also elsewhere on the board
DIO_31: J1.36; also elsewhere on the board
DIO_EN: X3.A11 (11); also elsewhere on the board
DIO_LEVEL_SELECT: X3.A13 (13); also elsewhere on the board
DIO_RESET: X3.A12 (12); also elsewhere on the board
EXT: J1.1, J1.20, JP-EXT-1.2, JP-EXT-2.2
GND: C26.2, C27.2, C120.2, C121.2, IC1.2 (GND), J1.18, J1.19, J1.MH1, J1.MH2, X3.A10 (10), X3.A14 (14), X3.A15 (15), X3.A16 (16), X3.A25 (25), X3.A30 (30), X3.A31 (31), X3.A32 (32), X3.B10 (10), X3.B14 (14), X3.B15 (15), X3.B16 (16), X3.B19 (19), X3.B22 (22), X3.B25 (25), X3.B30 (30), X3.B31 (31), X3.B32 (32); also elsewhere on the board
unnamed: JP-3V3-2.2, X3.B1 (1)
unnamed: JP-3V3-1.2, X3.A1 (1)
RP2040_RST: X3.B18 (18); also elsewhere on the board
SPI0_CS0: X3.A2 (2); also elsewhere on the board
SPI0_CS1: X3.A3 (3); also elsewhere on the board
SPI0_MISO: X3.A7 (7), X3.B7 (7); also elsewhere on the board
SPI0_MOSI: X3.A6 (6), X3.B6 (6); also elsewhere on the board
SPI0_SCK: X3.A5 (5), X3.B5 (5); also elsewhere on the board
SPI1_CS: X3.A29 (29), X3.B29 (29); also elsewhere on the board
SPI1_MISO: X3.A26 (26), X3.B26 (26); also elsewhere on the board
SPI1_MOSI: X3.A27 (27), X3.B27 (27); also elsewhere on the board
SPI1_SCK: X3.A28 (28), X3.B28 (28); also elsewhere on the board
SWCLK: X3.B23 (23); also elsewhere on the board
SWDIO: X3.B24 (24); also elsewhere on the board
UART0_RX: X3.B20 (20); also elsewhere on the board
UART0_TX: X3.B21 (21); also elsewhere on the board
VBUS: D1.A; also elsewhere on the board

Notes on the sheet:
3.3V SYSTEM LDO
Enable SWD Debugging on Raspberry Pi: Install OpenOCD (sudo apt install openocd) Configure /boot/config.txt to enable GPIO-based debugging.
BOARD CONNECTOR
DIGITAL CONNECTOR
POWER AND OUTPUT
Rev 1.0
David Sipos / DvidMakesThings

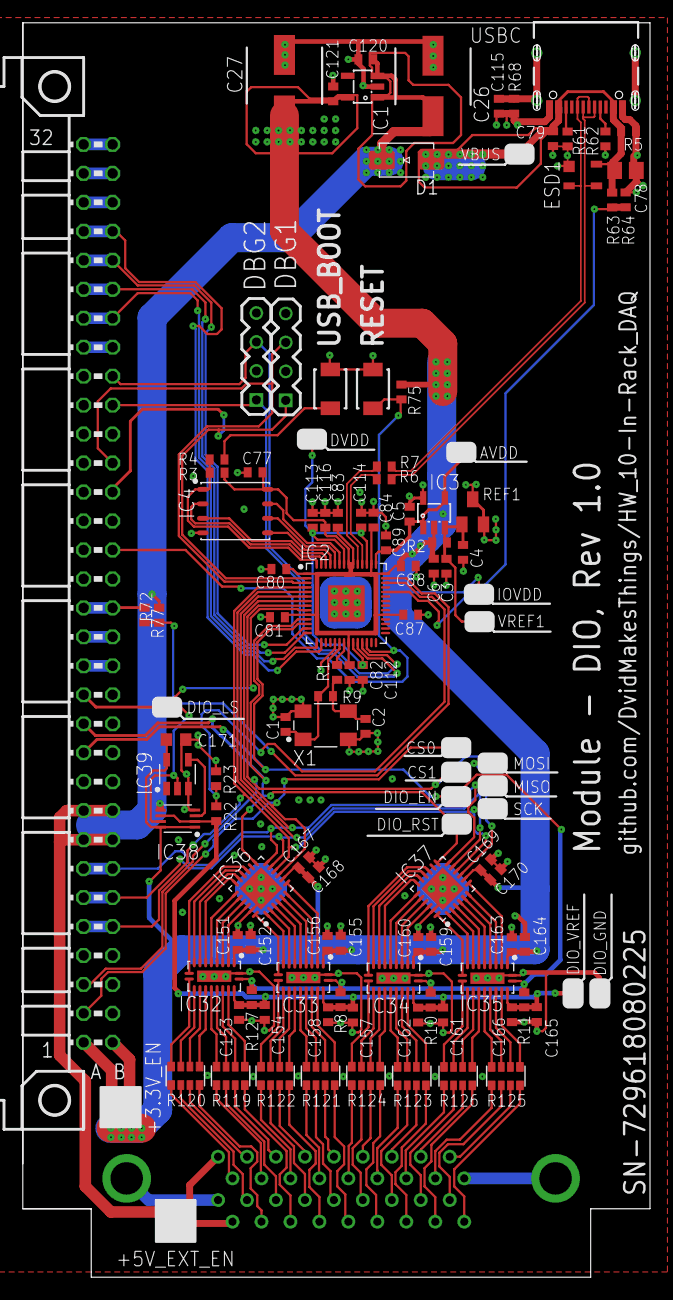
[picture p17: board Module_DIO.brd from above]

Board: 4 copper layers, 55.0 x 110.0 mm, 119 parts (1 on the bottom side), 145 nets.

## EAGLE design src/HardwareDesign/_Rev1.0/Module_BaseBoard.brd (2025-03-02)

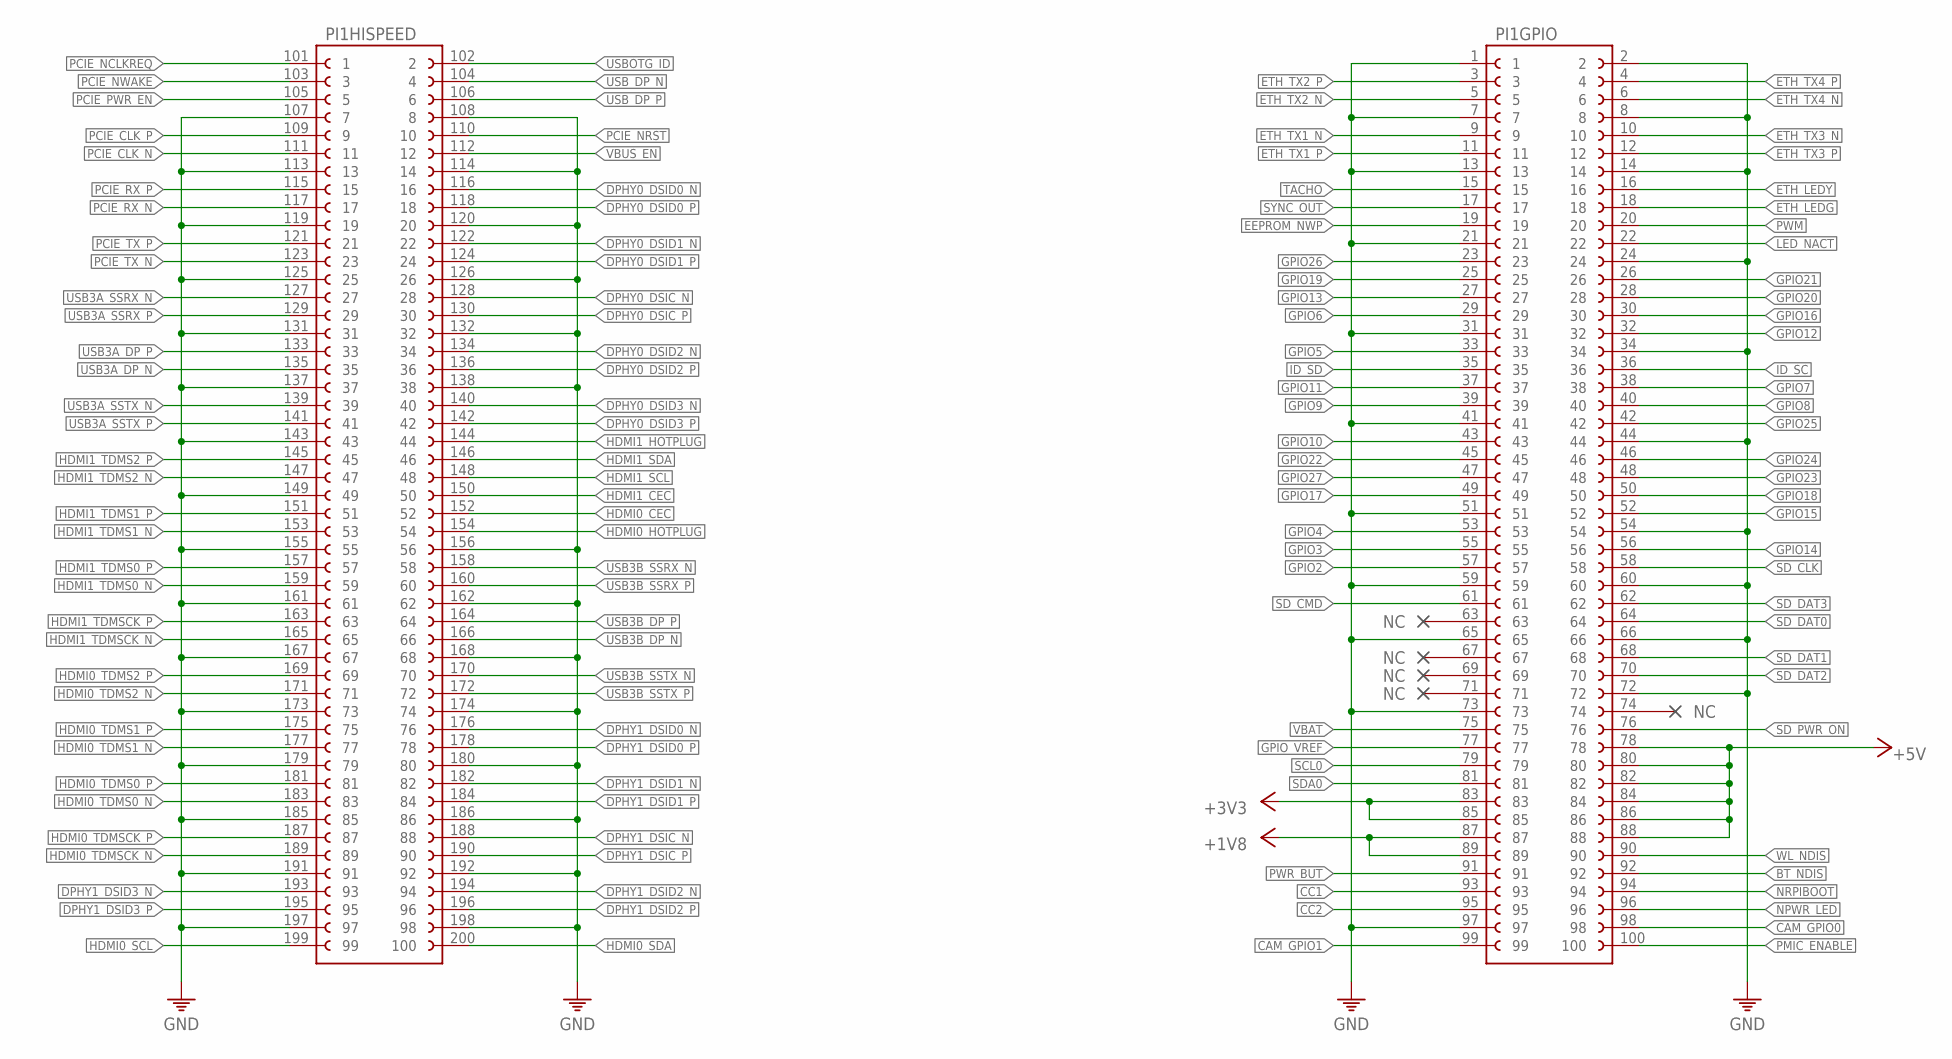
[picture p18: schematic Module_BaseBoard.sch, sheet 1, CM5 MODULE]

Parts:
PI1: RASPBERRY_CM5; CM5

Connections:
+1V8: PI1.87, PI1.89; also elsewhere on the board
+3V3: PI1.83, PI1.85; also elsewhere on the board
+5V: PI1.78, PI1.80, PI1.82, PI1.84, PI1.86, PI1.88; also elsewhere on the board
BT_NDIS: PI1.92; also elsewhere on the board
CAM_GPIO0: PI1.98; also elsewhere on the board
CAM_GPIO1: PI1.99; also elsewhere on the board
CC1: PI1.93; also elsewhere on the board
CC2: PI1.95; also elsewhere on the board
DPHY0_DSIC_N: PI1.128 (28); also elsewhere on the board
DPHY0_DSIC_P: PI1.130 (30); also elsewhere on the board
DPHY0_DSID0_N: PI1.116 (16); also elsewhere on the board
DPHY0_DSID0_P: PI1.118 (18); also elsewhere on the board
DPHY0_DSID1_N: PI1.122 (22); also elsewhere on the board
DPHY0_DSID1_P: PI1.124 (24); also elsewhere on the board
DPHY0_DSID2_N: PI1.134 (34); also elsewhere on the board
DPHY0_DSID2_P: PI1.136 (36); also elsewhere on the board
DPHY0_DSID3_N: PI1.140 (40); also elsewhere on the board
DPHY0_DSID3_P: PI1.142 (42); also elsewhere on the board
DPHY1_DSIC_N: PI1.188 (88); also elsewhere on the board
DPHY1_DSIC_P: PI1.190 (90); also elsewhere on the board
DPHY1_DSID0_N: PI1.176 (76); also elsewhere on the board
DPHY1_DSID0_P: PI1.178 (78); also elsewhere on the board
DPHY1_DSID1_N: PI1.182 (82); also elsewhere on the board
DPHY1_DSID1_P: PI1.184 (84); also elsewhere on the board
DPHY1_DSID2_N: PI1.194 (94); also elsewhere on the board
DPHY1_DSID2_P: PI1.196 (96); also elsewhere on the board
DPHY1_DSID3_N: PI1.193 (93); also elsewhere on the board
DPHY1_DSID3_P: PI1.195 (95); also elsewhere on the board
EEPROM_NWP: PI1.19; also elsewhere on the board
ETH_LEDG: PI1.18; also elsewhere on the board
ETH_LEDY: PI1.16; also elsewhere on the board
ETH_TX1_N: PI1.9; also elsewhere on the board
ETH_TX1_P: PI1.11; also elsewhere on the board
ETH_TX2_N: PI1.5; also elsewhere on the board
ETH_TX2_P: PI1.3; also elsewhere on the board
ETH_TX3_N: PI1.10; also elsewhere on the board
ETH_TX3_P: PI1.12; also elsewhere on the board
ETH_TX4_N: PI1.6; also elsewhere on the board
ETH_TX4_P: PI1.4; also elsewhere on the board
GND: PI1.1, PI1.2, PI1.7, PI1.8, PI1.13, PI1.14, PI1.21, PI1.24, PI1.31, PI1.34, PI1.41, PI1.44, PI1.51, PI1.54, PI1.59, PI1.60, PI1.65, PI1.66, PI1.72, PI1.73, PI1.97, PI1.107 (7), PI1.108 (8), PI1.113 (13), PI1.114 (14), PI1.119 (19), PI1.120 (20), PI1.125 (25), PI1.126 (26), PI1.131 (31), PI1.132 (32), PI1.137 (37), PI1.138 (38), PI1.143 (43), PI1.149 (49), PI1.155 (55), PI1.156 (56), PI1.161 (61), PI1.162 (62), PI1.167 (67), PI1.168 (68), PI1.173 (73), PI1.174 (74), PI1.179 (79), PI1.180 (80), PI1.185 (85), PI1.186 (86), PI1.191 (91), PI1.192 (92), PI1.197 (97), PI1.198 (98); also elsewhere on the board
GPIO2: PI1.57; also elsewhere on the board
GPIO3: PI1.55; also elsewhere on the board
GPIO4: PI1.53; also elsewhere on the board
GPIO5: PI1.33; also elsewhere on the board
GPIO6: PI1.29; also elsewhere on the board
GPIO7: PI1.38; also elsewhere on the board
GPIO8: PI1.40; also elsewhere on the board
GPIO9: PI1.39; also elsewhere on the board
GPIO10: PI1.43; also elsewhere on the board
GPIO11: PI1.37; also elsewhere on the board
GPIO12: PI1.32; also elsewhere on the board
GPIO13: PI1.27; also elsewhere on the board
GPIO14: PI1.56; also elsewhere on the board
GPIO15: PI1.52; also elsewhere on the board
GPIO16: PI1.30; also elsewhere on the board
GPIO17: PI1.49; also elsewhere on the board
GPIO18: PI1.50; also elsewhere on the board
GPIO19: PI1.25; also elsewhere on the board
GPIO20: PI1.28; also elsewhere on the board
GPIO21: PI1.26; also elsewhere on the board
GPIO22: PI1.45; also elsewhere on the board
GPIO23: PI1.48; also elsewhere on the board
GPIO24: PI1.46; also elsewhere on the board
GPIO25: PI1.42; also elsewhere on the board
GPIO26: PI1.23; also elsewhere on the board
GPIO27: PI1.47; also elsewhere on the board
GPIO_VREF: PI1.77; also elsewhere on the board
HDMI0_CEC: PI1.152 (52); also elsewhere on the board
HDMI0_HOTPLUG: PI1.154 (54); also elsewhere on the board
HDMI0_SCL: PI1.199 (99); also elsewhere on the board
HDMI0_SDA: PI1.200 (100); also elsewhere on the board
HDMI0_TDMS0_N: PI1.183 (83); also elsewhere on the board
HDMI0_TDMS0_P: PI1.181 (81); also elsewhere on the board
HDMI0_TDMS1_N: PI1.177 (77); also elsewhere on the board
HDMI0_TDMS1_P: PI1.175 (75); also elsewhere on the board
HDMI0_TDMS2_N: PI1.171 (71); also elsewhere on the board
HDMI0_TDMS2_P: PI1.169 (69); also elsewhere on the board
HDMI0_TDMSCK_N: PI1.189 (89); also elsewhere on the board
HDMI0_TDMSCK_P: PI1.187 (87); also elsewhere on the board
HDMI1_CEC: PI1.150 (50); also elsewhere on the board
HDMI1_HOTPLUG: PI1.144 (44); also elsewhere on the board
HDMI1_SCL: PI1.148 (48); also elsewhere on the board
HDMI1_SDA: PI1.146 (46); also elsewhere on the board
HDMI1_TDMS0_N: PI1.159 (59); also elsewhere on the board
HDMI1_TDMS0_P: PI1.157 (57); also elsewhere on the board
HDMI1_TDMS1_N: PI1.153 (53); also elsewhere on the board
HDMI1_TDMS1_P: PI1.151 (51); also elsewhere on the board
HDMI1_TDMS2_N: PI1.147 (47); also elsewhere on the board
HDMI1_TDMS2_P: PI1.145 (45); also elsewhere on the board
HDMI1_TDMSCK_N: PI1.165 (65); also elsewhere on the board
HDMI1_TDMSCK_P: PI1.163 (63); also elsewhere on the board
ID_SC: PI1.36; also elsewhere on the board
ID_SD: PI1.35; also elsewhere on the board
LED_NACT: PI1.22
NPWR_LED: PI1.96; also elsewhere on the board
NRPIBOOT: PI1.94; also elsewhere on the board
PCIE_CLK_N: PI1.111 (11); also elsewhere on the board
PCIE_CLK_P: PI1.109 (9); also elsewhere on the board
PCIE_NCLKREQ: PI1.101 (1); also elsewhere on the board
PCIE_NRST: PI1.110 (10); also elsewhere on the board
PCIE_NWAKE: PI1.103 (3); also elsewhere on the board
PCIE_PWR_EN: PI1.105 (5); also elsewhere on the board
PCIE_RX_N: PI1.117 (17); also elsewhere on the board
PCIE_RX_P: PI1.115 (15); also elsewhere on the board
PCIE_TX_N: PI1.123 (23); also elsewhere on the board
PCIE_TX_P: PI1.121 (21); also elsewhere on the board
PMIC_ENABLE: PI1.100; also elsewhere on the board
PWM: PI1.20; also elsewhere on the board
PWR_BUT: PI1.91; also elsewhere on the board
SCL0: PI1.79; also elsewhere on the board
SDA0: PI1.81; also elsewhere on the board
SD_CLK: PI1.58; also elsewhere on the board
SD_CMD: PI1.61; also elsewhere on the board
SD_DAT0: PI1.64; also elsewhere on the board
SD_DAT1: PI1.68; also elsewhere on the board
SD_DAT2: PI1.70; also elsewhere on the board
SD_DAT3: PI1.62; also elsewhere on the board
SD_PWR_ON: PI1.76; also elsewhere on the board
SYNC_OUT: PI1.17; also elsewhere on the board
TACHO: PI1.15; also elsewhere on the board
USB3A_DP_N: PI1.135 (35); also elsewhere on the board
USB3A_DP_P: PI1.133 (33); also elsewhere on the board
USB3A_SSRX_N: PI1.127 (27); also elsewhere on the board
USB3A_SSRX_P: PI1.129 (29); also elsewhere on the board
USB3A_SSTX_N: PI1.139 (39); also elsewhere on the board
USB3A_SSTX_P: PI1.141 (41); also elsewhere on the board
USB3B_DP_N: PI1.166 (66); also elsewhere on the board
USB3B_DP_P: PI1.164 (64); also elsewhere on the board
USB3B_SSRX_N: PI1.158 (58); also elsewhere on the board
USB3B_SSRX_P: PI1.160 (60); also elsewhere on the board
USB3B_SSTX_N: PI1.170 (70); also elsewhere on the board
USB3B_SSTX_P: PI1.172 (72); also elsewhere on the board
USBOTG_ID: PI1.102 (2); also elsewhere on the board
USB_DP_N: PI1.104 (4); also elsewhere on the board
USB_DP_P: PI1.106 (6); also elsewhere on the board
VBAT: PI1.75
VBUS_EN: PI1.112 (12); also elsewhere on the board
WL_NDIS: PI1.90; also elsewhere on the board

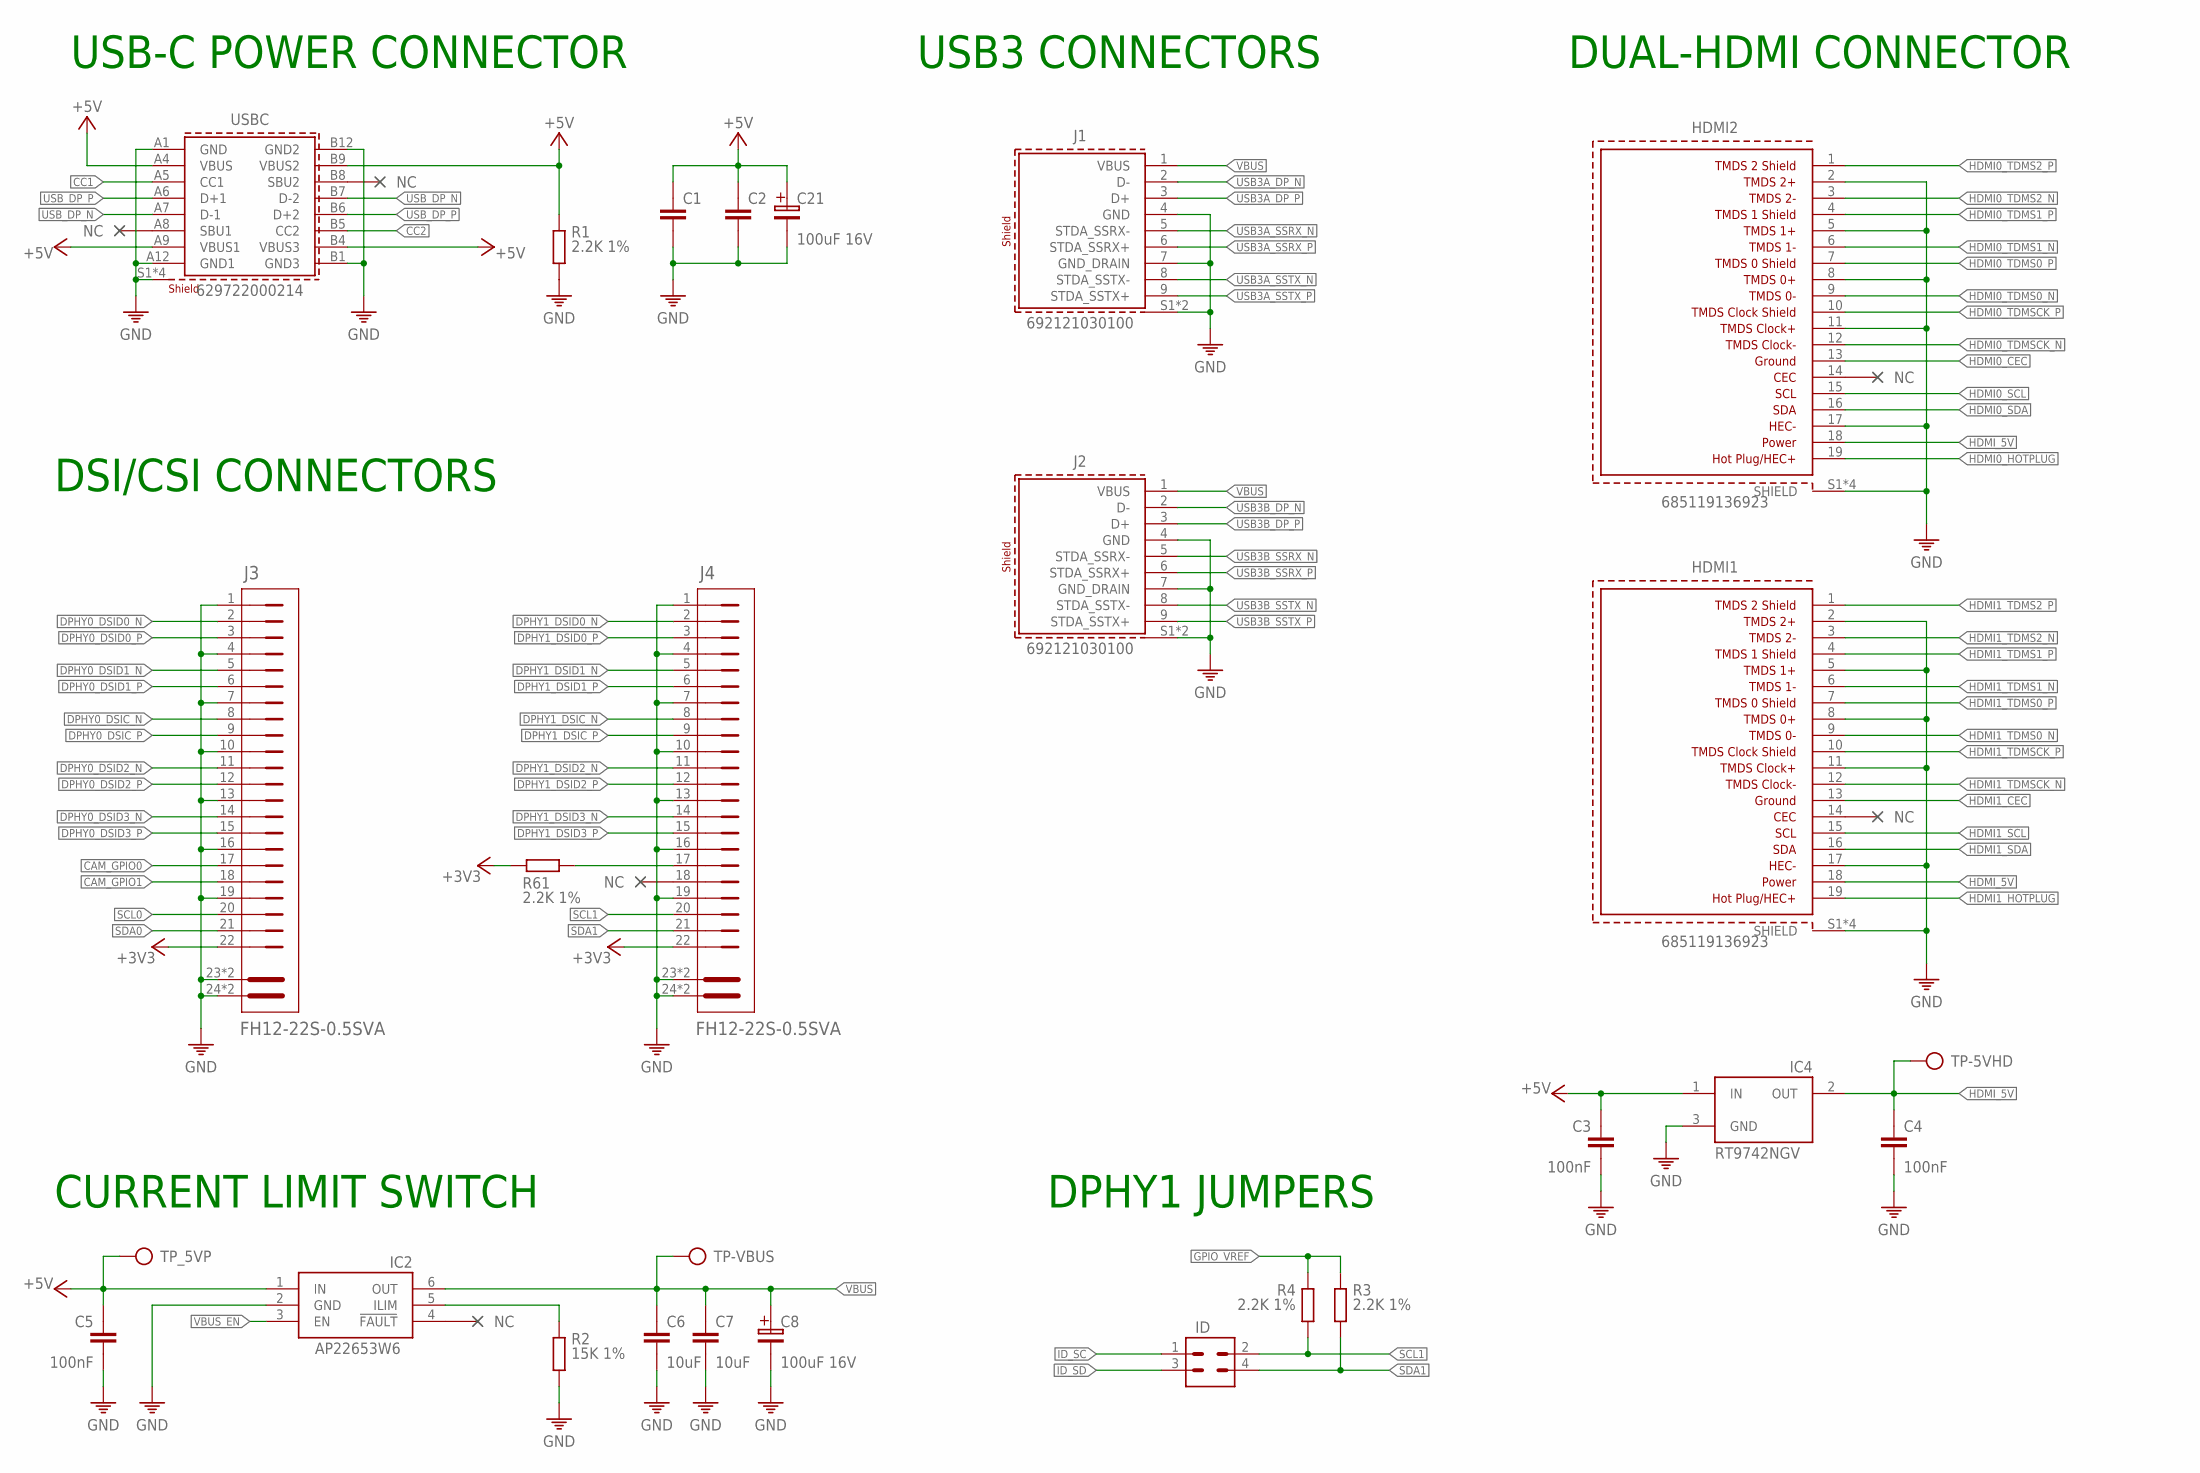
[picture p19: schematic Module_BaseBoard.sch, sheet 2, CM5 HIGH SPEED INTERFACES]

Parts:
C1, C2: C-0402; C0402
C3, C4, C5: 100nF; C0402
C6, C7: 10uF; C0805
C8, C21: 100uF 16V; 100UF-16V
HDMI1, HDMI2: 685119136923
IC2: AP22653W6; SOT23-6
IC4: RT9742NGV; SOT23
ID: CON-2X2; 2X2
J1, J2: 692121030100
J3, J4: FH12-22S-0.5SVA; FH12-22S-0.5SH
R1, R3, R4, R61: 2.2K 1%; 0402
R2: 15K 1%; 0402
TP-5VHD: TP
TP-VBUS: TP
TP_5VP: TP
USBC: 629722000214

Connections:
+3V3: J3.22, J4.22, R61.2; also elsewhere on the board
+5V: C1.1, C2.1, C3.1, C5.1, C21.1, IC2.1 (IN), IC4.1 (IN), R1.1, TP_5VP.TP, USBC.A4 (VBUS), USBC.A9 (VBUS1), USBC.B4 (VBUS3), USBC.B9 (VBUS2); also elsewhere on the board
CAM_GPIO0: J3.17; also elsewhere on the board
CAM_GPIO1: J3.18; also elsewhere on the board
CC1: USBC.A5 (CC1); also elsewhere on the board
CC2: USBC.B5 (CC2); also elsewhere on the board
DPHY0_DSIC_N: J3.8; also elsewhere on the board
DPHY0_DSIC_P: J3.9; also elsewhere on the board
DPHY0_DSID0_N: J3.2; also elsewhere on the board
DPHY0_DSID0_P: J3.3; also elsewhere on the board
DPHY0_DSID1_N: J3.5; also elsewhere on the board
DPHY0_DSID1_P: J3.6; also elsewhere on the board
DPHY0_DSID2_N: J3.11; also elsewhere on the board
DPHY0_DSID2_P: J3.12; also elsewhere on the board
DPHY0_DSID3_N: J3.14; also elsewhere on the board
DPHY0_DSID3_P: J3.15; also elsewhere on the board
DPHY1_DSIC_N: J4.8; also elsewhere on the board
DPHY1_DSIC_P: J4.9; also elsewhere on the board
DPHY1_DSID0_N: J4.2; also elsewhere on the board
DPHY1_DSID0_P: J4.3; also elsewhere on the board
DPHY1_DSID1_N: J4.5; also elsewhere on the board
DPHY1_DSID1_P: J4.6; also elsewhere on the board
DPHY1_DSID2_N: J4.11; also elsewhere on the board
DPHY1_DSID2_P: J4.12; also elsewhere on the board
DPHY1_DSID3_N: J4.14; also elsewhere on the board
DPHY1_DSID3_P: J4.15; also elsewhere on the board
GND: C1.2, C2.2, C3.2, C4.2, C5.2, C6.2, C7.2, C8.2, C21.2, HDMI1.2 (TMDS2+), HDMI1.5 (TMDSDATA1+), HDMI1.8 (TMDS0+), HDMI1.11 (TMDSCLOCK+), HDMI1.17 (UTILITY/HEAC+), HDMI1.S1 (SHIELD), HDMI1.S2 (SHIELD), HDMI1.S3 (SHIELD), HDMI1.S4 (SHIELD), HDMI2.2 (TMDS2+), HDMI2.5 (TMDSDATA1+), HDMI2.8 (TMDS0+), HDMI2.11 (TMDSCLOCK+), HDMI2.17 (UTILITY/HEAC+), HDMI2.S1 (SHIELD), HDMI2.S2 (SHIELD), HDMI2.S3 (SHIELD), HDMI2.S4 (SHIELD), IC2.2 (GND), IC4.3 (GND), J1.4 (GND), J1.7 (GND_DRAIN), J1.S1 (SHIELD), J1.S2 (SHIELD), J2.4 (GND), J2.7 (GND_DRAIN), J2.S1 (SHIELD), J2.S2 (SHIELD), J3.1, J3.4, J3.7, J3.10, J3.13, J3.16, J3.19, J3.23 (MH1), J3.24 (MH2), J3.25 (MH1), J3.26 (MH2), J4.1, J4.4, J4.7, J4.10, J4.13, J4.16, J4.19, J4.23 (MH1), J4.24 (MH2), J4.25 (MH1), J4.26 (MH2), R1.2, R2.2, USBC.A1 (GND), USBC.A12 (GND1), USBC.B1 (GND3), USBC.B12 (GND2), USBC.S1 (SHIELD), USBC.S2 (SHIELD), USBC.S3 (SHIELD), USBC.S4 (SHIELD); also elsewhere on the board
GPIO_VREF: R3.1, R4.1; also elsewhere on the board
HDMI0_CEC: HDMI2.13 (GROUND); also elsewhere on the board
HDMI0_HOTPLUG: HDMI2.19 (HOTPLUG/HEC+); also elsewhere on the board
HDMI0_SCL: HDMI2.15 (SCL); also elsewhere on the board
HDMI0_SDA: HDMI2.16 (SDA); also elsewhere on the board
HDMI0_TDMS0_N: HDMI2.9 (TMDS0-); also elsewhere on the board
HDMI0_TDMS0_P: HDMI2.7 (TMDS0SHIELD); also elsewhere on the board
HDMI0_TDMS1_N: HDMI2.6 (TMDS1-); also elsewhere on the board
HDMI0_TDMS1_P: HDMI2.4 (TMDS1SHIELD); also elsewhere on the board
HDMI0_TDMS2_N: HDMI2.3 (TMDS2-); also elsewhere on the board
HDMI0_TDMS2_P: HDMI2.1 (TMDS2SHIELD); also elsewhere on the board
HDMI0_TDMSCK_N: HDMI2.12 (TMDSCLOCK-); also elsewhere on the board
HDMI0_TDMSCK_P: HDMI2.10 (TMDSCLOCKSHIELD); also elsewhere on the board
HDMI1_CEC: HDMI1.13 (GROUND); also elsewhere on the board
HDMI1_HOTPLUG: HDMI1.19 (HOTPLUG/HEC+); also elsewhere on the board
HDMI1_SCL: HDMI1.15 (SCL); also elsewhere on the board
HDMI1_SDA: HDMI1.16 (SDA); also elsewhere on the board
HDMI1_TDMS0_N: HDMI1.9 (TMDS0-); also elsewhere on the board
HDMI1_TDMS0_P: HDMI1.7 (TMDS0SHIELD); also elsewhere on the board
HDMI1_TDMS1_N: HDMI1.6 (TMDS1-); also elsewhere on the board
HDMI1_TDMS1_P: HDMI1.4 (TMDS1SHIELD); also elsewhere on the board
HDMI1_TDMS2_N: HDMI1.3 (TMDS2-); also elsewhere on the board
HDMI1_TDMS2_P: HDMI1.1 (TMDS2SHIELD); also elsewhere on the board
HDMI1_TDMSCK_N: HDMI1.12 (TMDSCLOCK-); also elsewhere on the board
HDMI1_TDMSCK_P: HDMI1.10 (TMDSCLOCKSHIELD); also elsewhere on the board
HDMI_5V: C4.1, HDMI1.18 (POWER), HDMI2.18 (POWER), IC4.2 (OUT), TP-5VHD.TP
ID_SC: ID.1; also elsewhere on the board
ID_SD: ID.3; also elsewhere on the board
unnamed: IC2.5 (ILIM), R2.1
unnamed: J4.17, R61.1
SCL0: J3.20; also elsewhere on the board
SCL1: ID.2, J4.20, R4.2
SDA0: J3.21; also elsewhere on the board
SDA1: ID.4, J4.21, R3.2
USB3A_DP_N: J1.2 (D-); also elsewhere on the board
USB3A_DP_P: J1.3 (D+); also elsewhere on the board
USB3A_SSRX_N: J1.5 (STDA_SSRX-); also elsewhere on the board
USB3A_SSRX_P: J1.6 (STDA_SSRX+); also elsewhere on the board
USB3A_SSTX_N: J1.8 (STDA_SSTX-); also elsewhere on the board
USB3A_SSTX_P: J1.9 (STDA_SSTX+); also elsewhere on the board
USB3B_DP_N: J2.2 (D-); also elsewhere on the board
USB3B_DP_P: J2.3 (D+); also elsewhere on the board
USB3B_SSRX_N: J2.5 (STDA_SSRX-); also elsewhere on the board
USB3B_SSRX_P: J2.6 (STDA_SSRX+); also elsewhere on the board
USB3B_SSTX_N: J2.8 (STDA_SSTX-); also elsewhere on the board
USB3B_SSTX_P: J2.9 (STDA_SSTX+); also elsewhere on the board
USB_DP_N: USBC.A7 (D-1), USBC.B7 (D-2); also elsewhere on the board
USB_DP_P: USBC.A6 (D+1), USBC.B6 (D+2); also elsewhere on the board
VBUS: C6.1, C7.1, C8.1, IC2.6 (OUT), J1.1 (VBUS), J2.1 (VBUS), TP-VBUS.TP
VBUS_EN: IC2.3 (EN); also elsewhere on the board

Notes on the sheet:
USB-C POWER CONNECTOR
USB3 CONNECTORS
DUAL-HDMI CONNECTOR
CURRENT LIMIT SWITCH
DPHY1 JUMPERS
DSI/CSI CONNECTORS

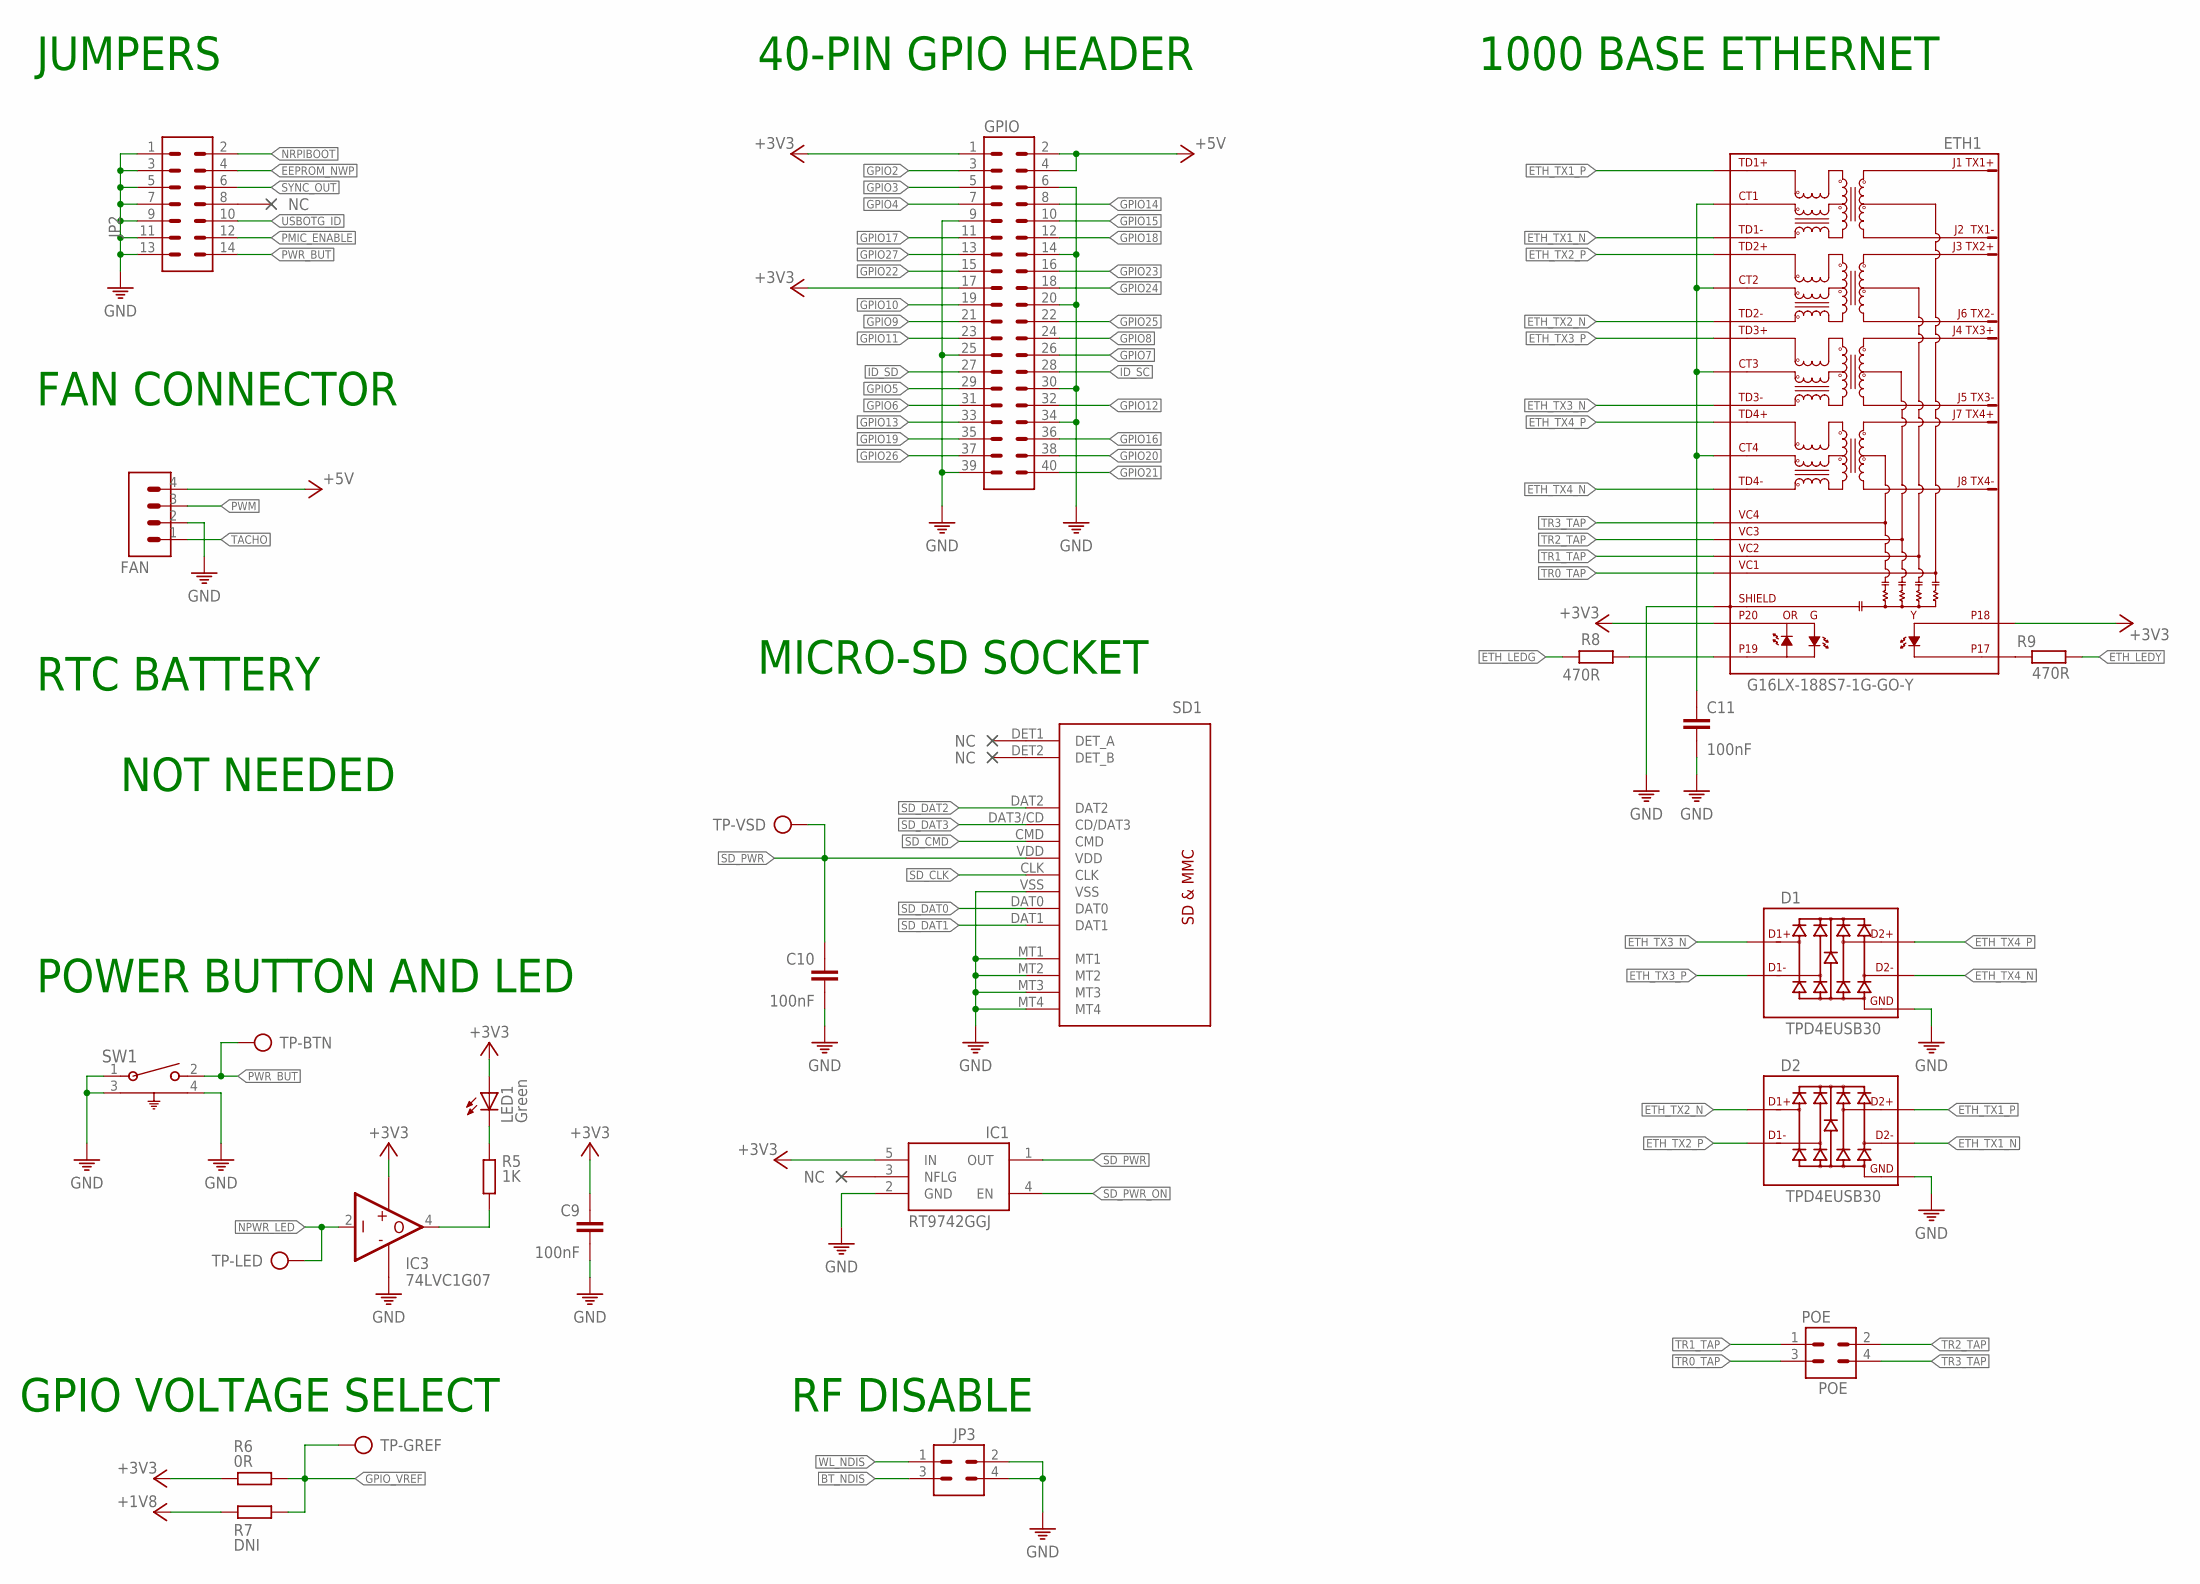
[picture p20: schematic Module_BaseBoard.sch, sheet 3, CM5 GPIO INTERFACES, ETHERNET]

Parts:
C9, C10, C11: 100nF; C0402
D1, D2: TPD4EUSB30; USON
ETH1: G16LX-188S7-1G-GO-Y; MAGJACK_POE
FAN: CON-1X4; 1X4
GPIO: CON-2X20; 2X20
IC1: RT9742GGJ; SOT23-5
IC3: 74LVC1G07; SOT23-5
JP2: CON-2X7; 2X7
JP3: CON-2X2; 2X2
LED1: Green; CHIPLED_0805
POE: POE; 2X2
R5: 1K; 0402
R6: 0R; 0402
R7: DNI; 0402
R8, R9: 470R; 0402
SD1: MICRO-SD; MICROSD
SW1: 1825027-8; SW2_1825027-C_TEC
TP-BTN: TP
TP-GREF: TP
TP-LED: TP
TP-VSD: TP

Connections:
+1V8: R7.1; also elsewhere on the board
+3V3: C9.1, ETH1.18, ETH1.20, GPIO.1, GPIO.17, IC1.5 (IN), IC3.5 (VCC), LED1.A, R6.1; also elsewhere on the board
+5V: FAN.4, GPIO.2, GPIO.4; also elsewhere on the board
BT_NDIS: JP3.3; also elsewhere on the board
EEPROM_NWP: JP2.4; also elsewhere on the board
ETH_LEDG: R8.1; also elsewhere on the board
ETH_LEDY: R9.2; also elsewhere on the board
ETH_TX1_N: D2.2 (D1-), D2.9 (D1-), ETH1.TD1-; also elsewhere on the board
ETH_TX1_P: D2.1 (D1+), D2.10 (D1+), ETH1.TD1+; also elsewhere on the board
ETH_TX2_N: D2.4 (D2+), D2.7 (D2+), ETH1.TD2-; also elsewhere on the board
ETH_TX2_P: D2.5 (D2-), D2.6 (D2-), ETH1.TD2+; also elsewhere on the board
ETH_TX3_N: D1.4 (D2+), D1.7 (D2+), ETH1.TD3-; also elsewhere on the board
ETH_TX3_P: D1.5 (D2-), D1.6 (D2-), ETH1.TD3+; also elsewhere on the board
ETH_TX4_N: D1.2 (D1-), D1.9 (D1-), ETH1.TD4-; also elsewhere on the board
ETH_TX4_P: D1.1 (D1+), D1.10 (D1+), ETH1.TD4+; also elsewhere on the board
GND: C9.2, C10.2, C11.2, D1.3 (GND), D1.8 (GND), D2.3 (GND), D2.8 (GND), ETH1.MH3 (SHIELD), ETH1.MH4 (SHIELD), FAN.2, GPIO.6, GPIO.9, GPIO.14, GPIO.20, GPIO.25, GPIO.30, GPIO.34, GPIO.39, IC1.2 (GND), IC3.3 (GND), JP2.1, JP2.3, JP2.5, JP2.7, JP2.9, JP2.11, JP2.13, JP3.2, JP3.4, SD1.MT1, SD1.MT2, SD1.MT3, SD1.MT4, SD1.VSS, SW1.1, SW1.3, SW1.4; also elsewhere on the board
GPIO2: GPIO.3; also elsewhere on the board
GPIO3: GPIO.5; also elsewhere on the board
GPIO4: GPIO.7; also elsewhere on the board
GPIO5: GPIO.29; also elsewhere on the board
GPIO6: GPIO.31; also elsewhere on the board
GPIO7: GPIO.26; also elsewhere on the board
GPIO8: GPIO.24; also elsewhere on the board
GPIO9: GPIO.21; also elsewhere on the board
GPIO10: GPIO.19; also elsewhere on the board
GPIO11: GPIO.23; also elsewhere on the board
GPIO12: GPIO.32; also elsewhere on the board
GPIO13: GPIO.33; also elsewhere on the board
GPIO14: GPIO.8; also elsewhere on the board
GPIO15: GPIO.10; also elsewhere on the board
GPIO16: GPIO.36; also elsewhere on the board
GPIO17: GPIO.11; also elsewhere on the board
GPIO18: GPIO.12; also elsewhere on the board
GPIO19: GPIO.35; also elsewhere on the board
GPIO20: GPIO.38; also elsewhere on the board
GPIO21: GPIO.40; also elsewhere on the board
GPIO22: GPIO.15; also elsewhere on the board
GPIO23: GPIO.16; also elsewhere on the board
GPIO24: GPIO.18; also elsewhere on the board
GPIO25: GPIO.22; also elsewhere on the board
GPIO26: GPIO.37; also elsewhere on the board
GPIO27: GPIO.13; also elsewhere on the board
GPIO_VREF: R6.2, R7.2, TP-GREF.TP; also elsewhere on the board
ID_SC: GPIO.28; also elsewhere on the board
ID_SD: GPIO.27; also elsewhere on the board
unnamed: LED1.C, R5.1
unnamed: IC3.4 (Y), R5.2
unnamed: C11.1, ETH1.CT1, ETH1.CT2, ETH1.CT3, ETH1.CT4
unnamed: ETH1.17, R9.1
unnamed: ETH1.19, R8.2
NPWR_LED: IC3.2 (A), TP-LED.TP; also elsewhere on the board
NRPIBOOT: JP2.2; also elsewhere on the board
PMIC_ENABLE: JP2.12; also elsewhere on the board
PWM: FAN.3; also elsewhere on the board
PWR_BUT: JP2.14, SW1.2, TP-BTN.TP; also elsewhere on the board
SD_CLK: SD1.CLK; also elsewhere on the board
SD_CMD: SD1.CMD; also elsewhere on the board
SD_DAT0: SD1.DAT0; also elsewhere on the board
SD_DAT1: SD1.DAT1; also elsewhere on the board
SD_DAT2: SD1.DAT2; also elsewhere on the board
SD_DAT3: SD1.DAT3/CD (CD/DAT3); also elsewhere on the board
SD_PWR: C10.1, IC1.1 (OUT), SD1.VDD, TP-VSD.TP
SD_PWR_ON: IC1.4 (EN); also elsewhere on the board
SYNC_OUT: JP2.6; also elsewhere on the board
TACHO: FAN.1; also elsewhere on the board
TR0_TAP: ETH1.VC1, POE.3
TR1_TAP: ETH1.VC2, POE.1
TR2_TAP: ETH1.VC3, POE.2
TR3_TAP: ETH1.VC4, POE.4
USBOTG_ID: JP2.10; also elsewhere on the board
WL_NDIS: JP3.1; also elsewhere on the board

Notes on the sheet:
JUMPERS
FAN CONNECTOR
RTC BATTERY
POWER BUTTON AND LED
GPIO VOLTAGE SELECT
40-PIN GPIO HEADER
MICRO-SD SOCKET
1000 BASE ETHERNET
RF DISABLE
NOT NEEDED

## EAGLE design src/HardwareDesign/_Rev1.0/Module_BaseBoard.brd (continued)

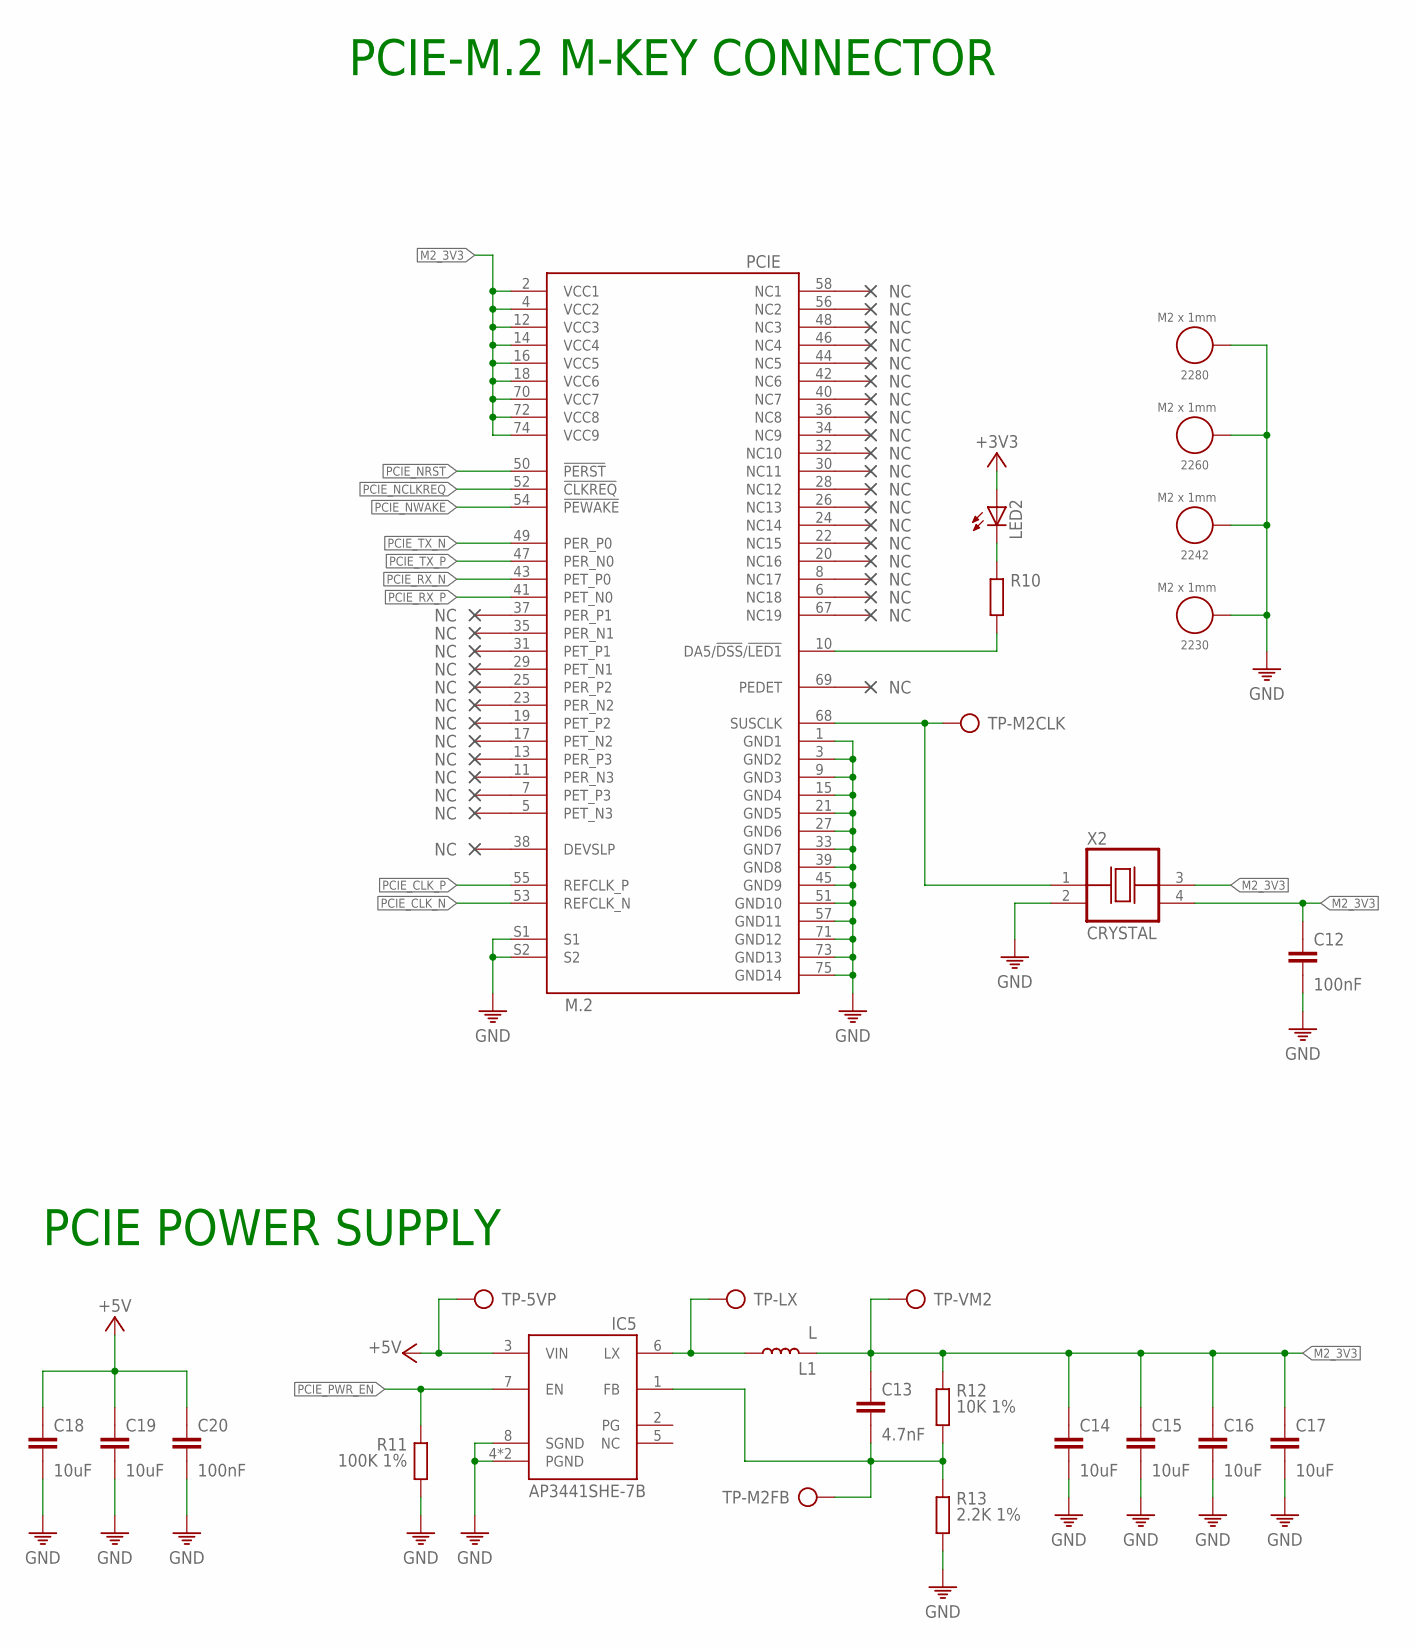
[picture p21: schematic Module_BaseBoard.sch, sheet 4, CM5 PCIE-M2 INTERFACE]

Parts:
2230, 2242, 2260, 2280: M2 x 1mm; WA-SMSI_9774010243
C12, C20: 100nF; C0402
C13: 4.7nF; C0402
C14, C15, C16, C17, C18, C19: 10uF; C0805
IC5: AP3441SHE-7B; SON50P201X201X56-9T90X170N
L1: L; SRR5228A
LED2: LEDCHIPLED_0805; CHIPLED_0805
PCIE: M.2
R10: R0402; 0402
R11: 100K 1%; 0402
R12: 10K 1%; 0402
R13: 2.2K 1%; 0402
TP-5VP: TP
TP-LX: TP
TP-M2CLK, TP-M2FB: TP
TP-VM2: TP
X2: CRYSTAL; OSCCC500X320X130

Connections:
+3V3: LED2.A; also elsewhere on the board
+5V: C18.1, C19.1, C20.1, IC5.3 (VIN), TP-5VP.TP; also elsewhere on the board
GND: 2230.1, 2242.1, 2260.1, 2280.1, C12.2, C14.2, C15.2, C16.2, C17.2, C18.2, C19.2, C20.2, IC5.4 (PGND), IC5.8 (SGND), IC5.9 (PGND), PCIE.1 (GND1), PCIE.3 (GND2), PCIE.9 (GND3), PCIE.15 (GND4), PCIE.21 (GND5), PCIE.27 (GND6), PCIE.33 (GND7), PCIE.39 (GND8), PCIE.45 (GND9), PCIE.51 (GND10), PCIE.57 (GND11), PCIE.71 (GND12), PCIE.73 (GND13), PCIE.75 (GND14), PCIE.S1, PCIE.S2, R11.2, R13.2, X2.2 (VSS); also elsewhere on the board
M2_3V3: C12.1, C13.1, C14.1, C15.1, C16.1, C17.1, L1.2, PCIE.2 (VCC1), PCIE.4 (VCC2), PCIE.12 (VCC3), PCIE.14 (VCC4), PCIE.16 (VCC5), PCIE.18 (VCC6), PCIE.70 (VCC7), PCIE.72 (VCC8), PCIE.74 (VCC9), R12.1, TP-VM2.TP, X2.3 (OUT), X2.4 (VDD)
unnamed: PCIE.10 (DA5/!DSS!/!LED1), R10.2
unnamed: LED2.C, R10.1
unnamed: IC5.6 (LX), L1.1, TP-LX.TP
unnamed: C13.2, IC5.1 (FB), R12.2, R13.1, TP-M2FB.TP
unnamed: PCIE.68 (SUSCLK), TP-M2CLK.TP, X2.1 (CON)
PCIE_CLK_N: PCIE.53 (REFCLK_N); also elsewhere on the board
PCIE_CLK_P: PCIE.55 (REFCLK_P); also elsewhere on the board
PCIE_NCLKREQ: PCIE.52 (!CLKREQ); also elsewhere on the board
PCIE_NRST: PCIE.50 (!PERST); also elsewhere on the board
PCIE_NWAKE: PCIE.54 (!PEWAKE); also elsewhere on the board
PCIE_PWR_EN: IC5.7 (EN), R11.1; also elsewhere on the board
PCIE_RX_N: PCIE.43 (PET_P0); also elsewhere on the board
PCIE_RX_P: PCIE.41 (PET_N0); also elsewhere on the board
PCIE_TX_N: PCIE.49 (PER_P0); also elsewhere on the board
PCIE_TX_P: PCIE.47 (PER_N0); also elsewhere on the board

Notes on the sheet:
PCIE-M.2 M-KEY CONNECTOR
PCIE POWER SUPPLY

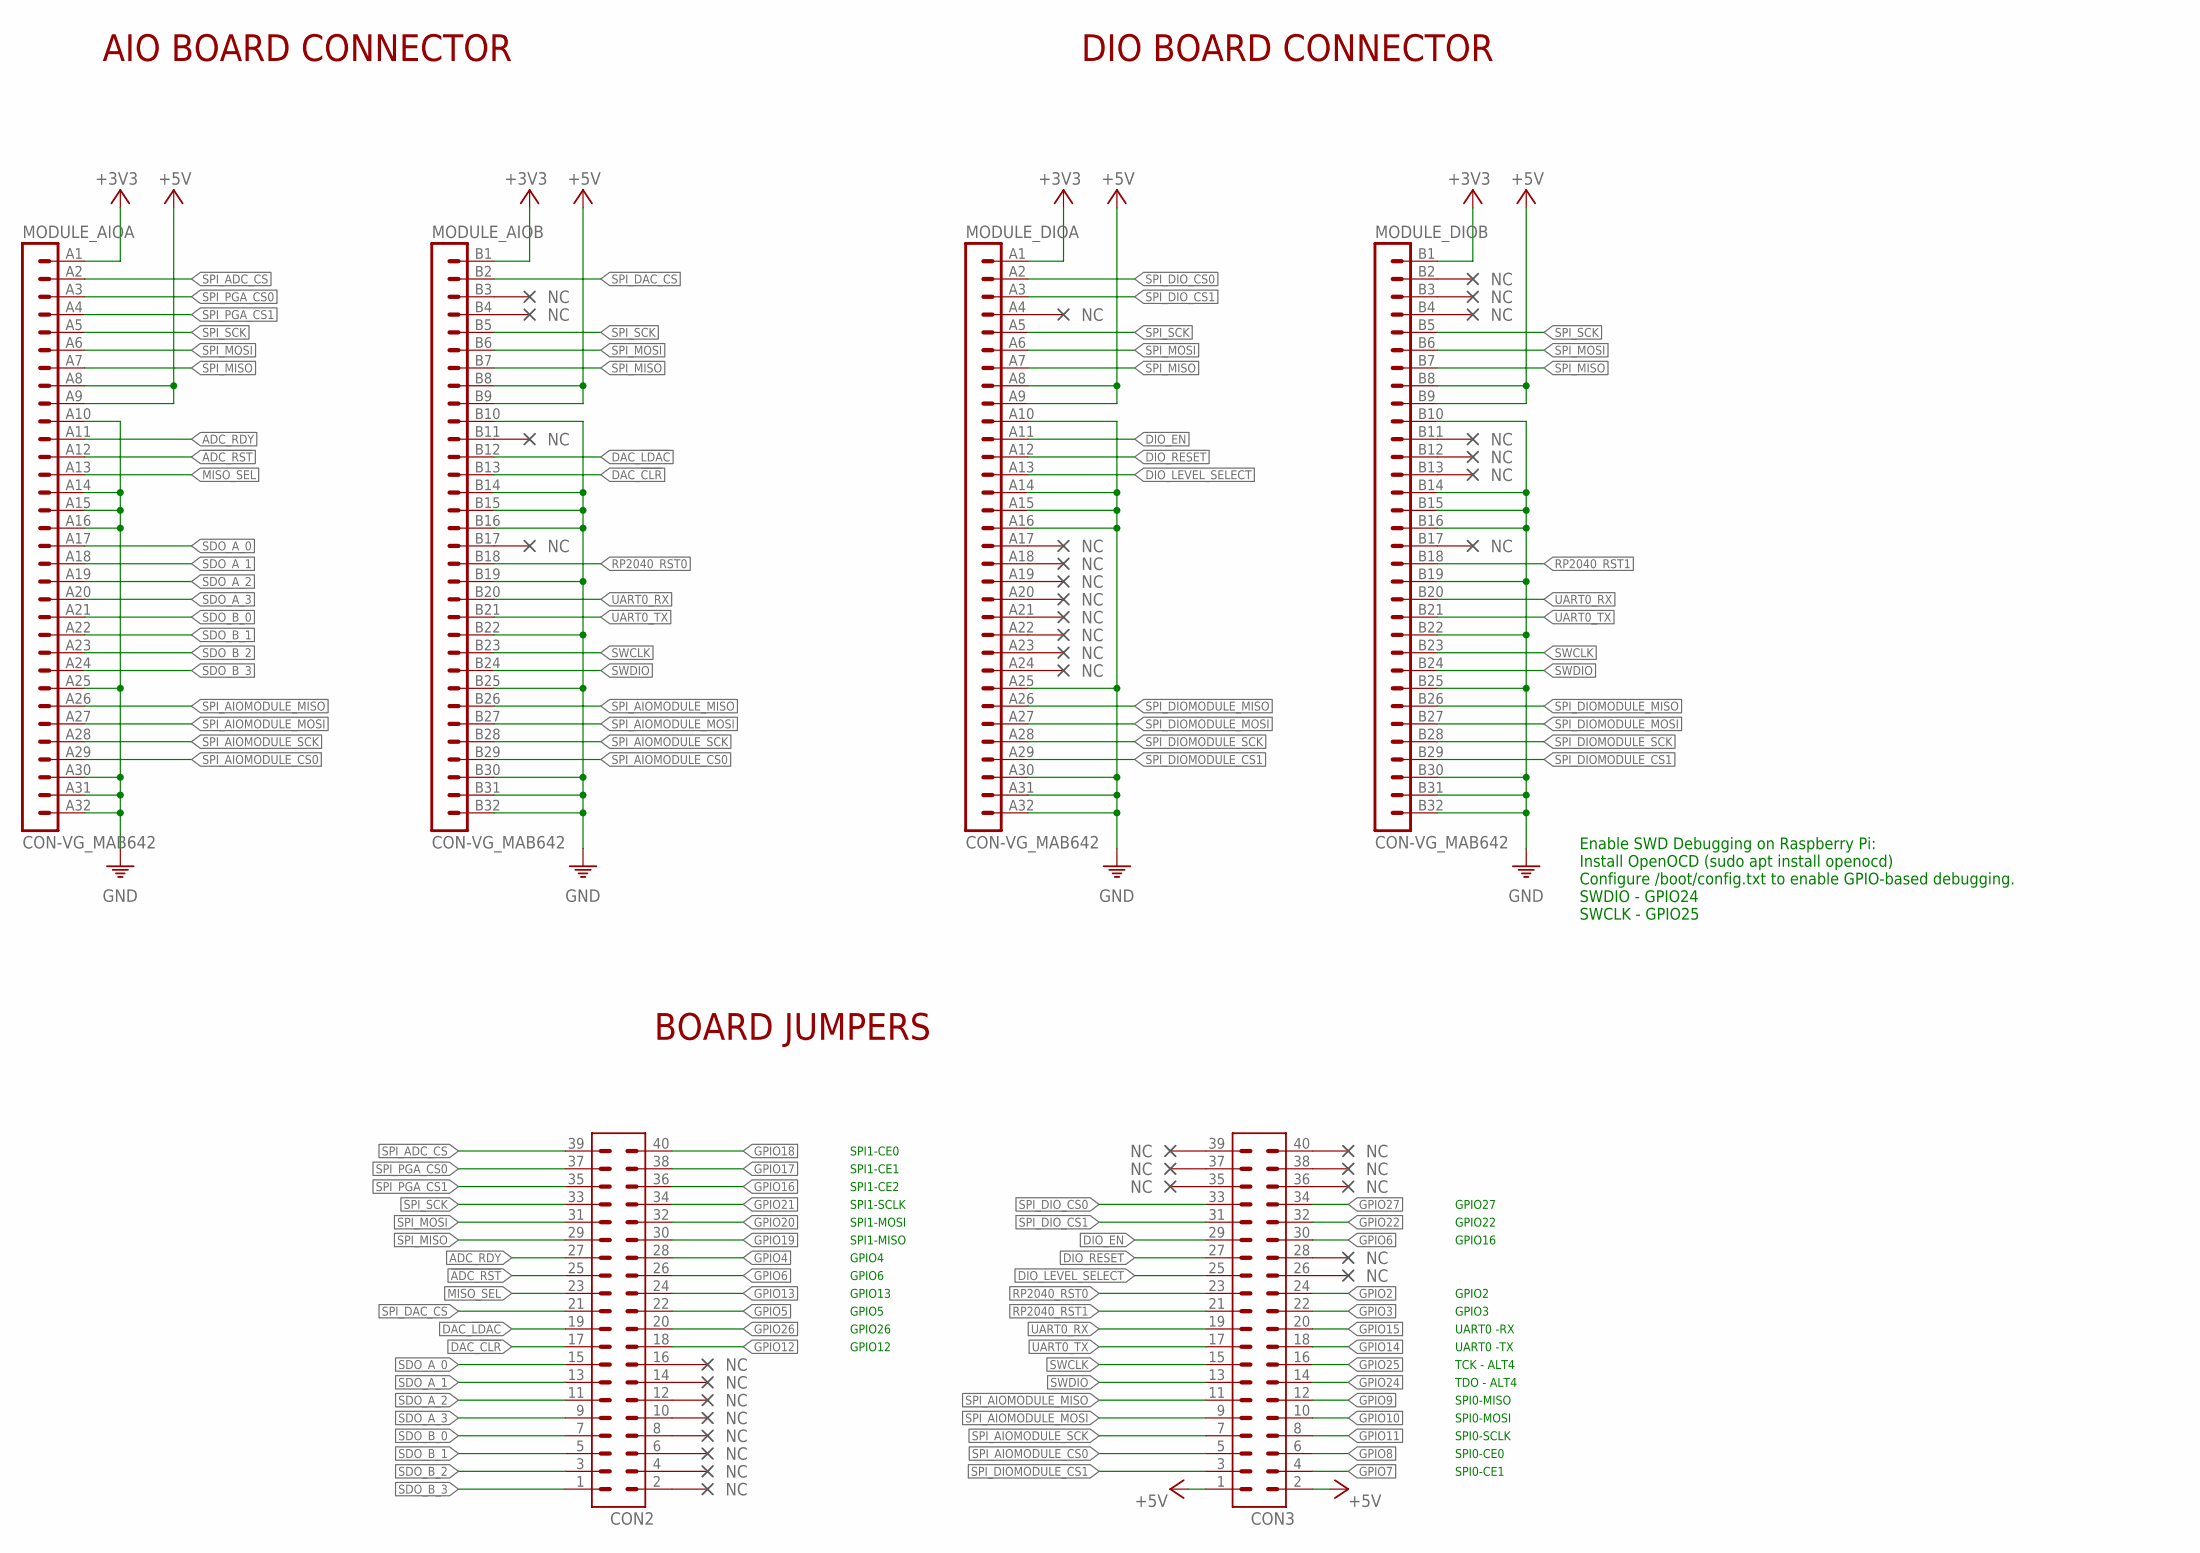
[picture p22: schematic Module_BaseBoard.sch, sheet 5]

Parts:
CON2, CON3: CON-2X20; 2X20
MODULE_AIO: CON-VG_MAB642; CON-VG-MAB64-RECEPTACLE
MODULE_DIO: CON-VG_MAB642; CON-VG-MAB64-RECEPTACLE

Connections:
!ADC_RST: CON2.25, MODULE_AIO.A12 (12)
+3V3: MODULE_AIO.A1 (1), MODULE_AIO.B1 (1), MODULE_DIO.A1 (1), MODULE_DIO.B1 (1); also elsewhere on the board
+5V: CON3.1, CON3.2, MODULE_AIO.A8 (8), MODULE_AIO.A9 (9), MODULE_AIO.B8 (8), MODULE_AIO.B9 (9), MODULE_DIO.A8 (8), MODULE_DIO.A9 (9), MODULE_DIO.B8 (8), MODULE_DIO.B9 (9); also elsewhere on the board
ADC_RDY: CON2.27, MODULE_AIO.A11 (11)
DAC_!CLR: CON2.17, MODULE_AIO.B13 (13)
DAC_!LDAC: CON2.19, MODULE_AIO.B12 (12)
DIO_EN: CON3.29, MODULE_DIO.A11 (11)
DIO_LEVEL_SELECT: CON3.25, MODULE_DIO.A13 (13)
DIO_RESET: CON3.27, MODULE_DIO.A12 (12)
GND: MODULE_AIO.A10 (10), MODULE_AIO.A14 (14), MODULE_AIO.A15 (15), MODULE_AIO.A16 (16), MODULE_AIO.A25 (25), MODULE_AIO.A30 (30), MODULE_AIO.A31 (31), MODULE_AIO.A32 (32), MODULE_AIO.B10 (10), MODULE_AIO.B14 (14), MODULE_AIO.B15 (15), MODULE_AIO.B16 (16), MODULE_AIO.B19 (19), MODULE_AIO.B22 (22), MODULE_AIO.B25 (25), MODULE_AIO.B30 (30), MODULE_AIO.B31 (31), MODULE_AIO.B32 (32), MODULE_DIO.A10 (10), MODULE_DIO.A14 (14), MODULE_DIO.A15 (15), MODULE_DIO.A16 (16), MODULE_DIO.A25 (25), MODULE_DIO.A30 (30), MODULE_DIO.A31 (31), MODULE_DIO.A32 (32), MODULE_DIO.B10 (10), MODULE_DIO.B14 (14), MODULE_DIO.B15 (15), MODULE_DIO.B16 (16), MODULE_DIO.B19 (19), MODULE_DIO.B22 (22), MODULE_DIO.B25 (25), MODULE_DIO.B30 (30), MODULE_DIO.B31 (31), MODULE_DIO.B32 (32); also elsewhere on the board
GPIO2: CON3.24; also elsewhere on the board
GPIO3: CON3.22; also elsewhere on the board
GPIO4: CON2.28; also elsewhere on the board
GPIO5: CON2.22; also elsewhere on the board
GPIO6: CON2.26, CON3.30; also elsewhere on the board
GPIO7: CON3.4; also elsewhere on the board
GPIO8: CON3.6; also elsewhere on the board
GPIO9: CON3.12; also elsewhere on the board
GPIO10: CON3.10; also elsewhere on the board
GPIO11: CON3.8; also elsewhere on the board
GPIO12: CON2.18; also elsewhere on the board
GPIO13: CON2.24; also elsewhere on the board
GPIO14: CON3.18; also elsewhere on the board
GPIO15: CON3.20; also elsewhere on the board
GPIO16: CON2.36; also elsewhere on the board
GPIO17: CON2.38; also elsewhere on the board
GPIO18: CON2.40; also elsewhere on the board
GPIO19: CON2.30; also elsewhere on the board
GPIO20: CON2.32; also elsewhere on the board
GPIO21: CON2.34; also elsewhere on the board
GPIO22: CON3.32; also elsewhere on the board
GPIO24: CON3.14; also elsewhere on the board
GPIO25: CON3.16; also elsewhere on the board
GPIO26: CON2.20; also elsewhere on the board
GPIO27: CON3.34; also elsewhere on the board
MISO_SEL: CON2.23, MODULE_AIO.A13 (13)
RP2040_RST0: CON3.23, MODULE_AIO.B18 (18)
RP2040_RST1: CON3.21, MODULE_DIO.B18 (18)
SDO_A_0: CON2.15, MODULE_AIO.A17 (17)
SDO_A_1: CON2.13, MODULE_AIO.A18 (18)
SDO_A_2: CON2.11, MODULE_AIO.A19 (19)
SDO_A_3: CON2.9, MODULE_AIO.A20 (20)
SDO_B_0: CON2.7, MODULE_AIO.A21 (21)
SDO_B_1: CON2.5, MODULE_AIO.A22 (22)
SDO_B_2: CON2.3, MODULE_AIO.A23 (23)
SDO_B_3: CON2.1, MODULE_AIO.A24 (24)
SPI_ADC_CS: CON2.39, MODULE_AIO.A2 (2)
SPI_AIOMODULE_CS0: CON3.5, MODULE_AIO.A29 (29), MODULE_AIO.B29 (29)
SPI_AIOMODULE_MISO: CON3.11, MODULE_AIO.A26 (26), MODULE_AIO.B26 (26)
SPI_AIOMODULE_MOSI: CON3.9, MODULE_AIO.A27 (27), MODULE_AIO.B27 (27)
SPI_AIOMODULE_SCK: CON3.7, MODULE_AIO.A28 (28), MODULE_AIO.B28 (28)
SPI_DAC_CS: CON2.21, MODULE_AIO.B2 (2)
SPI_DIOMODULE_CS1: CON3.3, MODULE_DIO.A29 (29), MODULE_DIO.B29 (29)
SPI_DIOMODULE_MISO: MODULE_DIO.A26 (26), MODULE_DIO.B26 (26)
SPI_DIOMODULE_MOSI: MODULE_DIO.A27 (27), MODULE_DIO.B27 (27)
SPI_DIOMODULE_SCK: MODULE_DIO.A28 (28), MODULE_DIO.B28 (28)
SPI_DIO_CS0: CON3.33, MODULE_DIO.A2 (2)
SPI_DIO_CS1: CON3.31, MODULE_DIO.A3 (3)
SPI_MISO: CON2.29, MODULE_AIO.A7 (7), MODULE_AIO.B7 (7), MODULE_DIO.A7 (7), MODULE_DIO.B7 (7)
SPI_MOSI: CON2.31, MODULE_AIO.A6 (6), MODULE_AIO.B6 (6), MODULE_DIO.A6 (6), MODULE_DIO.B6 (6)
SPI_PGA_CS0: CON2.37, MODULE_AIO.A3 (3)
SPI_PGA_CS1: CON2.35, MODULE_AIO.A4 (4)
SPI_SCK: CON2.33, MODULE_AIO.A5 (5), MODULE_AIO.B5 (5), MODULE_DIO.A5 (5), MODULE_DIO.B5 (5)
SWCLK: CON3.15, MODULE_AIO.B23 (23), MODULE_DIO.B23 (23)
SWDIO: CON3.13, MODULE_AIO.B24 (24), MODULE_DIO.B24 (24)
UART0_RX: CON3.19, MODULE_AIO.B20 (20), MODULE_DIO.B20 (20)
UART0_TX: CON3.17, MODULE_AIO.B21 (21), MODULE_DIO.B21 (21)

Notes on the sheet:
AIO BOARD CONNECTOR
Enable SWD Debugging on Raspberry Pi: Install OpenOCD (sudo apt install openocd) Configure /boot/config.txt to enable GPIO-based debugging. SWDIO - GPIO24 SWCLK - GPIO25
DIO BOARD CONNECTOR
BOARD JUMPERS
SPI1-CE0
SPI1-CE1
SPI1-CE2
SPI1-SCLK
SPI1-MOSI
SPI1-MISO
GPIO5
GPIO27
GPIO22
TDO - ALT4
TCK - ALT4
UART0 -RX
UART0 -TX
SPI0-MISO
SPI0-MOSI
SPI0-SCLK
SPI0-CE0
SPI0-CE1
GPIO4
GPIO6
GPIO13
GPIO26
GPIO12
GPIO16
GPIO2
GPIO3

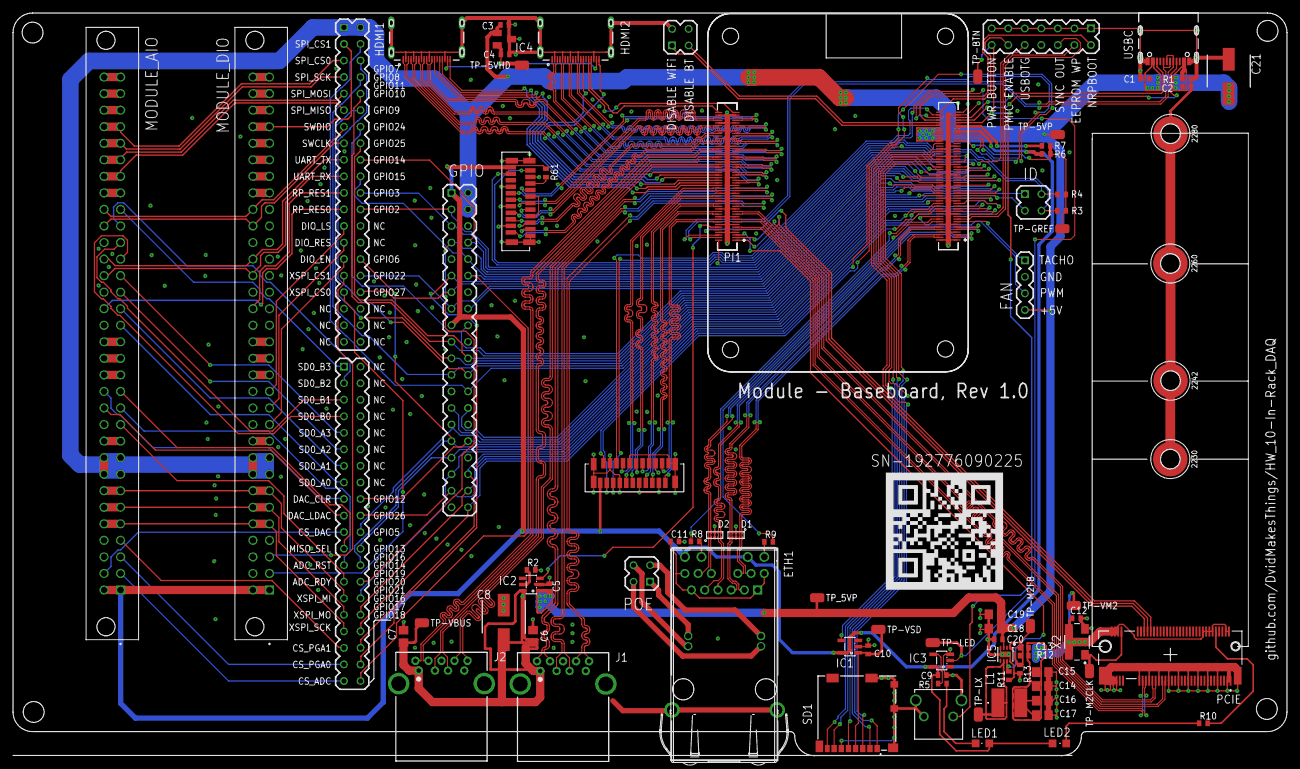
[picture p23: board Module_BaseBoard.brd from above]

Board: 4 copper layers, 195.6 x 114.0 mm, 84 parts (0 on the bottom side), 197 nets.

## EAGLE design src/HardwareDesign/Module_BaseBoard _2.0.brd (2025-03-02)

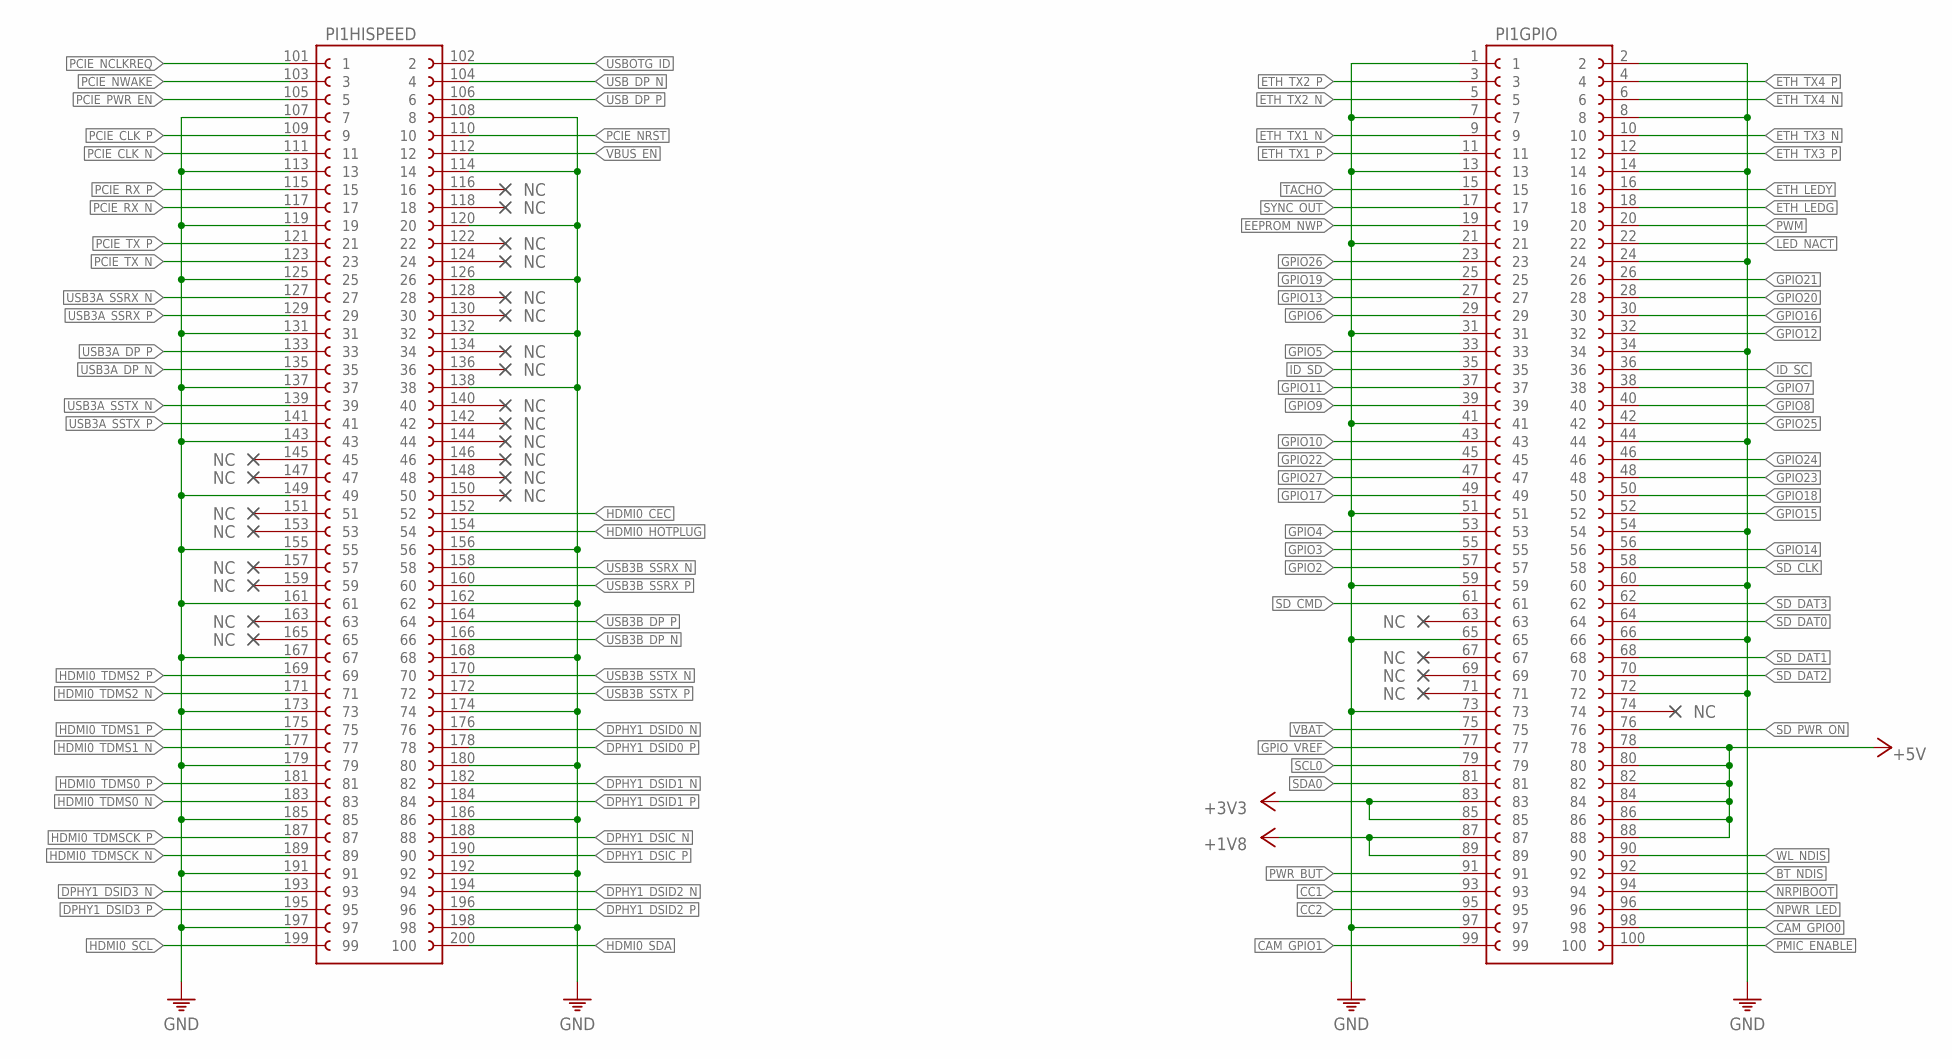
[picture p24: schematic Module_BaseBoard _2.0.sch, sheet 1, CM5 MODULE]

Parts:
PI1: RASPBERRY_CM5; CM5

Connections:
+1V8: PI1.87, PI1.89; also elsewhere on the board
+3V3: PI1.83, PI1.85; also elsewhere on the board
+5V: PI1.78, PI1.80, PI1.82, PI1.84, PI1.86, PI1.88; also elsewhere on the board
BT_NDIS: PI1.92
CAM_GPIO0: PI1.98; also elsewhere on the board
CAM_GPIO1: PI1.99; also elsewhere on the board
CC1: PI1.93; also elsewhere on the board
CC2: PI1.95; also elsewhere on the board
DPHY1_DSIC_N: PI1.188 (88); also elsewhere on the board
DPHY1_DSIC_P: PI1.190 (90); also elsewhere on the board
DPHY1_DSID0_N: PI1.176 (76); also elsewhere on the board
DPHY1_DSID0_P: PI1.178 (78); also elsewhere on the board
DPHY1_DSID1_N: PI1.182 (82); also elsewhere on the board
DPHY1_DSID1_P: PI1.184 (84); also elsewhere on the board
DPHY1_DSID2_N: PI1.194 (94); also elsewhere on the board
DPHY1_DSID2_P: PI1.196 (96); also elsewhere on the board
DPHY1_DSID3_N: PI1.193 (93); also elsewhere on the board
DPHY1_DSID3_P: PI1.195 (95); also elsewhere on the board
EEPROM_NWP: PI1.19; also elsewhere on the board
ETH_LEDG: PI1.18; also elsewhere on the board
ETH_LEDY: PI1.16; also elsewhere on the board
ETH_TX1_N: PI1.9; also elsewhere on the board
ETH_TX1_P: PI1.11; also elsewhere on the board
ETH_TX2_N: PI1.5; also elsewhere on the board
ETH_TX2_P: PI1.3; also elsewhere on the board
ETH_TX3_N: PI1.10; also elsewhere on the board
ETH_TX3_P: PI1.12; also elsewhere on the board
ETH_TX4_N: PI1.6; also elsewhere on the board
ETH_TX4_P: PI1.4; also elsewhere on the board
GND: PI1.1, PI1.2, PI1.7, PI1.8, PI1.13, PI1.14, PI1.21, PI1.24, PI1.31, PI1.34, PI1.41, PI1.44, PI1.51, PI1.54, PI1.59, PI1.60, PI1.65, PI1.66, PI1.72, PI1.73, PI1.97, PI1.107 (7), PI1.108 (8), PI1.113 (13), PI1.114 (14), PI1.119 (19), PI1.120 (20), PI1.125 (25), PI1.126 (26), PI1.131 (31), PI1.132 (32), PI1.137 (37), PI1.138 (38), PI1.143 (43), PI1.149 (49), PI1.155 (55), PI1.156 (56), PI1.161 (61), PI1.162 (62), PI1.167 (67), PI1.168 (68), PI1.173 (73), PI1.174 (74), PI1.179 (79), PI1.180 (80), PI1.185 (85), PI1.186 (86), PI1.191 (91), PI1.192 (92), PI1.197 (97), PI1.198 (98); also elsewhere on the board
GPIO2: PI1.57; also elsewhere on the board
GPIO3: PI1.55; also elsewhere on the board
GPIO4: PI1.53; also elsewhere on the board
GPIO5: PI1.33; also elsewhere on the board
GPIO6: PI1.29; also elsewhere on the board
GPIO7: PI1.38; also elsewhere on the board
GPIO8: PI1.40; also elsewhere on the board
GPIO9: PI1.39; also elsewhere on the board
GPIO10: PI1.43; also elsewhere on the board
GPIO11: PI1.37; also elsewhere on the board
GPIO12: PI1.32; also elsewhere on the board
GPIO13: PI1.27; also elsewhere on the board
GPIO14: PI1.56; also elsewhere on the board
GPIO15: PI1.52; also elsewhere on the board
GPIO16: PI1.30; also elsewhere on the board
GPIO17: PI1.49; also elsewhere on the board
GPIO18: PI1.50; also elsewhere on the board
GPIO19: PI1.25; also elsewhere on the board
GPIO20: PI1.28; also elsewhere on the board
GPIO21: PI1.26; also elsewhere on the board
GPIO22: PI1.45; also elsewhere on the board
GPIO23: PI1.48; also elsewhere on the board
GPIO24: PI1.46; also elsewhere on the board
GPIO25: PI1.42; also elsewhere on the board
GPIO26: PI1.23; also elsewhere on the board
GPIO27: PI1.47; also elsewhere on the board
GPIO_VREF: PI1.77; also elsewhere on the board
HDMI0_CEC: PI1.152 (52); also elsewhere on the board
HDMI0_HOTPLUG: PI1.154 (54); also elsewhere on the board
HDMI0_SCL: PI1.199 (99); also elsewhere on the board
HDMI0_SDA: PI1.200 (100); also elsewhere on the board
HDMI0_TDMS0_N: PI1.183 (83); also elsewhere on the board
HDMI0_TDMS0_P: PI1.181 (81); also elsewhere on the board
HDMI0_TDMS1_N: PI1.177 (77); also elsewhere on the board
HDMI0_TDMS1_P: PI1.175 (75); also elsewhere on the board
HDMI0_TDMS2_N: PI1.171 (71); also elsewhere on the board
HDMI0_TDMS2_P: PI1.169 (69); also elsewhere on the board
HDMI0_TDMSCK_N: PI1.189 (89); also elsewhere on the board
HDMI0_TDMSCK_P: PI1.187 (87); also elsewhere on the board
ID_SC: PI1.36; also elsewhere on the board
ID_SD: PI1.35; also elsewhere on the board
LED_NACT: PI1.22; also elsewhere on the board
NPWR_LED: PI1.96; also elsewhere on the board
NRPIBOOT: PI1.94; also elsewhere on the board
PCIE_CLK_N: PI1.111 (11); also elsewhere on the board
PCIE_CLK_P: PI1.109 (9); also elsewhere on the board
PCIE_NCLKREQ: PI1.101 (1); also elsewhere on the board
PCIE_NRST: PI1.110 (10); also elsewhere on the board
PCIE_NWAKE: PI1.103 (3); also elsewhere on the board
PCIE_PWR_EN: PI1.105 (5); also elsewhere on the board
PCIE_RX_N: PI1.117 (17); also elsewhere on the board
PCIE_RX_P: PI1.115 (15); also elsewhere on the board
PCIE_TX_N: PI1.123 (23); also elsewhere on the board
PCIE_TX_P: PI1.121 (21); also elsewhere on the board
PMIC_ENABLE: PI1.100; also elsewhere on the board
PWM: PI1.20
PWR_BUT: PI1.91; also elsewhere on the board
SCL0: PI1.79
SDA0: PI1.81
SD_CLK: PI1.58; also elsewhere on the board
SD_CMD: PI1.61; also elsewhere on the board
SD_DAT0: PI1.64; also elsewhere on the board
SD_DAT1: PI1.68; also elsewhere on the board
SD_DAT2: PI1.70; also elsewhere on the board
SD_DAT3: PI1.62; also elsewhere on the board
SD_PWR_ON: PI1.76; also elsewhere on the board
SYNC_OUT: PI1.17; also elsewhere on the board
TACHO: PI1.15
USB3A_DP_N: PI1.135 (35); also elsewhere on the board
USB3A_DP_P: PI1.133 (33); also elsewhere on the board
USB3A_SSRX_N: PI1.127 (27); also elsewhere on the board
USB3A_SSRX_P: PI1.129 (29); also elsewhere on the board
USB3A_SSTX_N: PI1.139 (39); also elsewhere on the board
USB3A_SSTX_P: PI1.141 (41); also elsewhere on the board
USB3B_DP_N: PI1.166 (66); also elsewhere on the board
USB3B_DP_P: PI1.164 (64); also elsewhere on the board
USB3B_SSRX_N: PI1.158 (58); also elsewhere on the board
USB3B_SSRX_P: PI1.160 (60); also elsewhere on the board
USB3B_SSTX_N: PI1.170 (70); also elsewhere on the board
USB3B_SSTX_P: PI1.172 (72); also elsewhere on the board
USBOTG_ID: PI1.102 (2); also elsewhere on the board
USB_DP_N: PI1.104 (4); also elsewhere on the board
USB_DP_P: PI1.106 (6); also elsewhere on the board
VBAT: PI1.75
VBUS_EN: PI1.112 (12); also elsewhere on the board
WL_NDIS: PI1.90

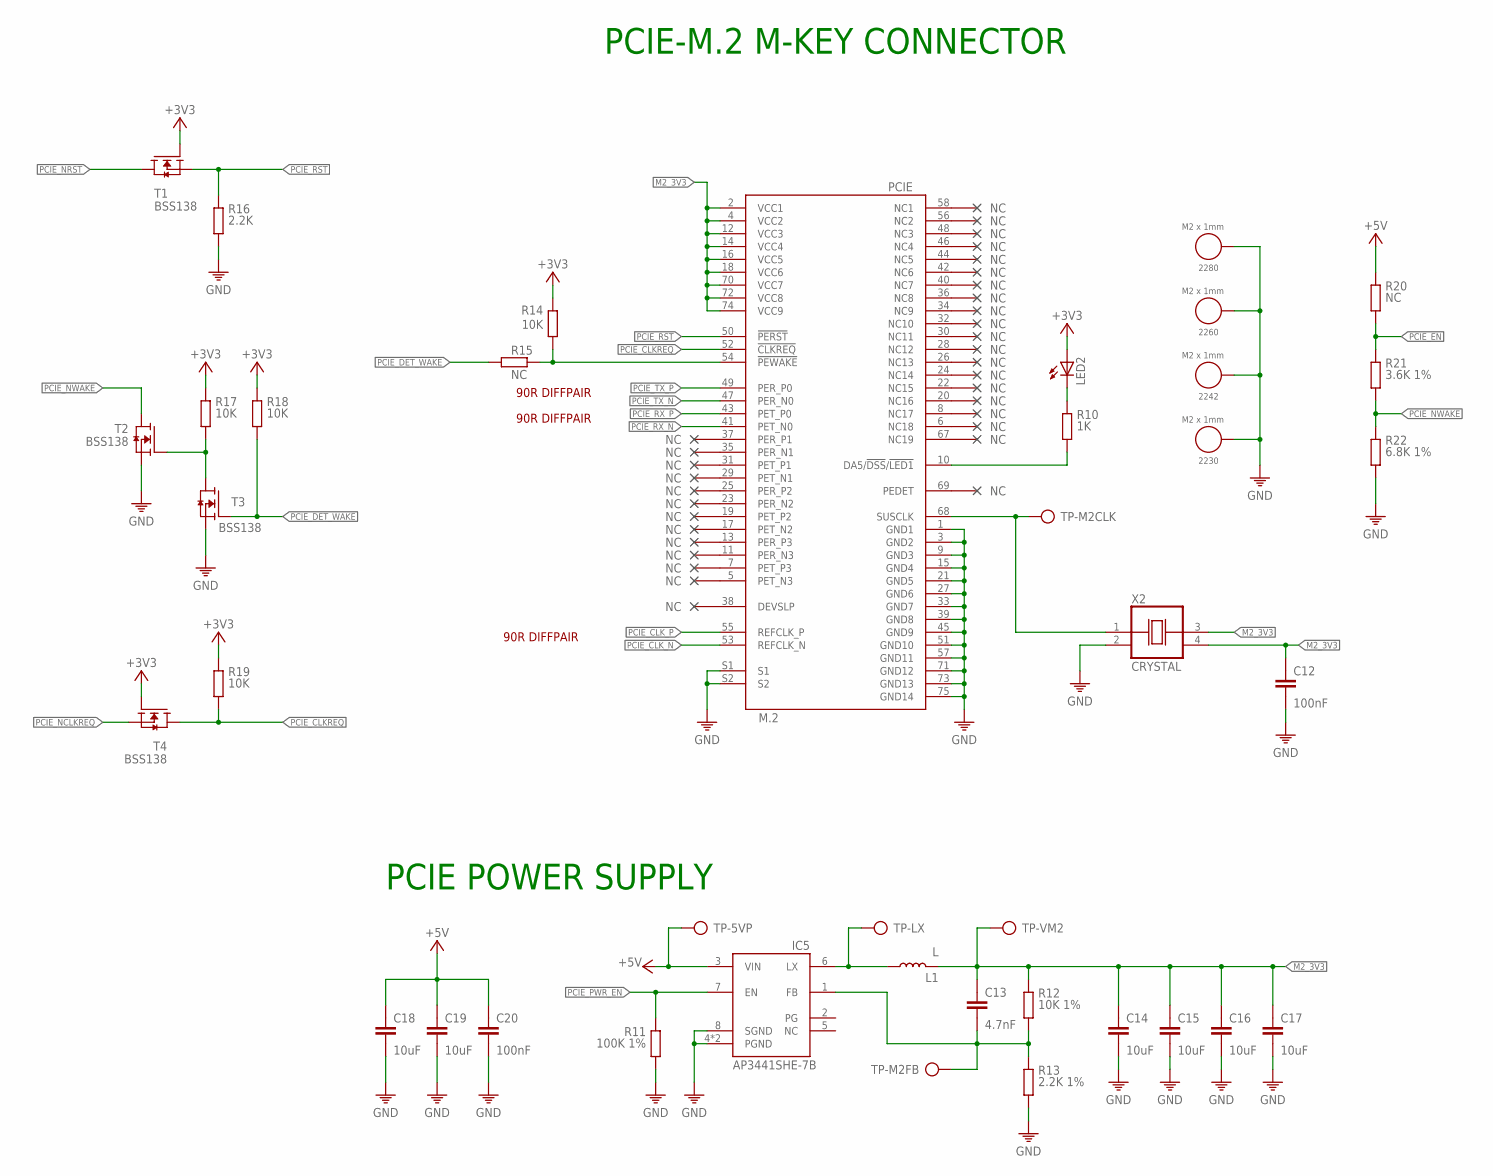
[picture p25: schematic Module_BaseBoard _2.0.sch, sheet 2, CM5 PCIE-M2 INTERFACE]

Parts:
2230, 2242, 2260, 2280: M2 x 1mm; WA-SMSI_9774010243
C12, C20: 100nF; C0402
C13: 4.7nF; C0402
C14, C15, C16, C17, C18, C19: 10uF; C0805
IC5: AP3441SHE-7B; SON50P201X201X56-9T90X170N
L1: L; SRR5228A
LED2: LEDCHIPLED_0805; CHIPLED_0805
PCIE: M.2; PCIE_M.2
R10: 1K; 0402
R11: 100K 1%; 0402
R12: 10K 1%; 0402
R13: 2.2K 1%; 0402
R14, R17, R18, R19: 10K; 0402
R15, R20: NC; 0402
R16: 2.2K; 0402
R21: 3.6K 1%; 0402
R22: 6.8K 1%; 0402
T1, T2, T3, T4: BSS138; SOT23
TP-5VP: TP
TP-LX: TP
TP-M2CLK, TP-M2FB: TP
TP-VM2: TP
X2: CRYSTAL; OSCCC500X320X130

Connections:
+3V3: LED2.A, R14.1, R17.1, R18.1, R19.1, T1.1 (G), T4.1 (G); also elsewhere on the board
+5V: C18.1, C19.1, C20.1, IC5.3 (VIN), R20.1, TP-5VP.TP; also elsewhere on the board
GND: 2230.1, 2242.1, 2260.1, 2280.1, C12.2, C14.2, C15.2, C16.2, C17.2, C18.2, C19.2, C20.2, IC5.4 (PGND), IC5.8 (SGND), IC5.9 (PGND), PCIE.1 (GND1), PCIE.3 (GND2), PCIE.9 (GND3), PCIE.15 (GND4), PCIE.21 (GND5), PCIE.27 (GND6), PCIE.33 (GND7), PCIE.39 (GND8), PCIE.45 (GND9), PCIE.51 (GND10), PCIE.57 (GND11), PCIE.71 (GND12), PCIE.73 (GND13), PCIE.75 (GND14), PCIE.S1, PCIE.S2, R11.2, R13.2, R16.2, R22.2, T2.2 (S), T3.2 (S), X2.2 (VSS); also elsewhere on the board
M2_3V3: C12.1, C13.1, C14.1, C15.1, C16.1, C17.1, L1.2, PCIE.2 (VCC1), PCIE.4 (VCC2), PCIE.12 (VCC3), PCIE.14 (VCC4), PCIE.16 (VCC5), PCIE.18 (VCC6), PCIE.70 (VCC7), PCIE.72 (VCC8), PCIE.74 (VCC9), R12.1, TP-VM2.TP, X2.3 (OUT), X2.4 (VDD)
unnamed: PCIE.10 (DA5/!DSS!/!LED1), R10.2
unnamed: LED2.C, R10.1
unnamed: IC5.6 (LX), L1.1, TP-LX.TP
unnamed: C13.2, IC5.1 (FB), R12.2, R13.1, TP-M2FB.TP
unnamed: PCIE.68 (SUSCLK), TP-M2CLK.TP, X2.1 (CON)
unnamed: PCIE.54 (!PEWAKE), R14.2, R15.1
unnamed: R17.2, T2.1 (G), T3.3 (D)
PCIE_CLKREQ: PCIE.52 (!CLKREQ), R19.2, T4.3 (D)
PCIE_CLK_N: PCIE.53 (REFCLK_N); also elsewhere on the board
PCIE_CLK_P: PCIE.55 (REFCLK_P); also elsewhere on the board
PCIE_DET_WAKE: R15.2, R18.2, T3.1 (G)
PCIE_EN: R20.2, R21.1
PCIE_NCLKREQ: T4.2 (S); also elsewhere on the board
PCIE_NRST: T1.3 (D); also elsewhere on the board
PCIE_NWAKE: R21.2, R22.1, T2.3 (D); also elsewhere on the board
PCIE_PWR_EN: IC5.7 (EN), R11.1; also elsewhere on the board
PCIE_RST: PCIE.50 (!PERST), R16.1, T1.2 (S)
PCIE_RX_N: PCIE.41 (PET_N0); also elsewhere on the board
PCIE_RX_P: PCIE.43 (PET_P0); also elsewhere on the board
PCIE_TX_N: PCIE.47 (PER_N0); also elsewhere on the board
PCIE_TX_P: PCIE.49 (PER_P0); also elsewhere on the board

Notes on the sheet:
PCIE-M.2 M-KEY CONNECTOR
PCIE POWER SUPPLY
90R DIFFPAIR

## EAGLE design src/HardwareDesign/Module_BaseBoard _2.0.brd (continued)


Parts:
C3, C4: 100nF; C0402
D3, D4, D7, D8, D9: TPD4EUSB30; USON
DISP0: FH12-22S-0.5SVA; FH12-22S-0.5SH
HDMI2: 685119136923
IC4: RT9742NGV; SOT23
ID: CON-2X2; 2X2
R3, R4: 2.2K 1%; 0402
TP-5VHD: TP

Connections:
+3V3: DISP0.22; also elsewhere on the board
+5V: C3.1, IC4.1 (IN); also elsewhere on the board
CAM_GPIO0: DISP0.17; also elsewhere on the board
CAM_GPIO1: DISP0.18; also elsewhere on the board
DPHY1_DSIC_N: D8.5 (D2-), D8.6 (D2-), DISP0.8; also elsewhere on the board
DPHY1_DSIC_P: D8.4 (D2+), D8.7 (D2+), DISP0.9; also elsewhere on the board
DPHY1_DSID0_N: D7.5 (D2-), D7.6 (D2-), DISP0.2; also elsewhere on the board
DPHY1_DSID0_P: D7.4 (D2+), D7.7 (D2+), DISP0.3; also elsewhere on the board
DPHY1_DSID1_N: D7.2 (D1-), D7.9 (D1-), DISP0.5; also elsewhere on the board
DPHY1_DSID1_P: D7.1 (D1+), D7.10 (D1+), DISP0.6; also elsewhere on the board
DPHY1_DSID2_N: D8.2 (D1-), D8.9 (D1-), DISP0.11; also elsewhere on the board
DPHY1_DSID2_P: D8.1 (D1+), D8.10 (D1+), DISP0.12; also elsewhere on the board
DPHY1_DSID3_N: D9.5 (D2-), D9.6 (D2-), DISP0.14; also elsewhere on the board
DPHY1_DSID3_P: D9.4 (D2+), D9.7 (D2+), DISP0.15; also elsewhere on the board
GND: C3.2, C4.2, D3.3 (GND), D3.8 (GND), D4.3 (GND), D4.8 (GND), D7.3 (GND), D7.8 (GND), D8.3 (GND), D8.8 (GND), D9.3 (GND), D9.8 (GND), DISP0.1, DISP0.4, DISP0.7, DISP0.10, DISP0.13, DISP0.16, DISP0.19, DISP0.23 (MH1), DISP0.24 (MH2), DISP0.25 (MH1), DISP0.26 (MH2), HDMI2.2 (TMDS2+), HDMI2.5 (TMDSDATA1+), HDMI2.8 (TMDS0+), HDMI2.11 (TMDSCLOCK+), HDMI2.17 (UTILITY/HEAC+), HDMI2.S1 (SHIELD), HDMI2.S2 (SHIELD), HDMI2.S3 (SHIELD), HDMI2.S4 (SHIELD), IC4.3 (GND); also elsewhere on the board
GPIO_VREF: R3.1, R4.1; also elsewhere on the board
HDMI0_CEC: HDMI2.13 (GROUND); also elsewhere on the board
HDMI0_HOTPLUG: HDMI2.19 (HOTPLUG/HEC+); also elsewhere on the board
HDMI0_SCL: HDMI2.15 (SCL); also elsewhere on the board
HDMI0_SDA: HDMI2.16 (SDA); also elsewhere on the board
HDMI0_TDMS0_N: D4.4 (D2+), D4.7 (D2+), HDMI2.9 (TMDS0-); also elsewhere on the board
HDMI0_TDMS0_P: D4.5 (D2-), D4.6 (D2-), HDMI2.7 (TMDS0SHIELD); also elsewhere on the board
HDMI0_TDMS1_N: D3.1 (D1+), D3.10 (D1+), HDMI2.6 (TMDS1-); also elsewhere on the board
HDMI0_TDMS1_P: D3.2 (D1-), D3.9 (D1-), HDMI2.4 (TMDS1SHIELD); also elsewhere on the board
HDMI0_TDMS2_N: D3.4 (D2+), D3.7 (D2+), HDMI2.3 (TMDS2-); also elsewhere on the board
HDMI0_TDMS2_P: D3.5 (D2-), D3.6 (D2-), HDMI2.1 (TMDS2SHIELD); also elsewhere on the board
HDMI0_TDMSCK_N: D4.1 (D1+), D4.10 (D1+), HDMI2.12 (TMDSCLOCK-); also elsewhere on the board
HDMI0_TDMSCK_P: D4.2 (D1-), D4.9 (D1-), HDMI2.10 (TMDSCLOCKSHIELD); also elsewhere on the board
HDMI_5V: C4.1, HDMI2.18 (POWER), IC4.2 (OUT), TP-5VHD.TP
ID_SC: ID.1; also elsewhere on the board
ID_SD: ID.3; also elsewhere on the board
SCL1: D9.1 (D1+), D9.10 (D1+), DISP0.20, ID.2, R4.2
SDA1: D9.2 (D1-), D9.9 (D1-), DISP0.21, ID.4, R3.2

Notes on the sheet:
HDMI0 CONNECTOR
100R DIFFPAIR
DSI/CSI CONNECTORS
DPHY1 JUMPERS
HDMI1 NOT INSTALLED


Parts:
C1: 100nF; C0805
C2, C6, C7, C23, C24, C25, C33, C34: 10uF; C0805
C5, C21, C32: 100nF; C0402
C8, C35: 100uF 16V; 100UF-16V
C22: 22uF; C0805
C26, C27: 10pF; C0402
D13, D14, D15, D16: TPD4EUSB30; USON
IC2, IC7: AP22653W6; SOT23-6
IC6: CH334; QFN24
JUSB4: CON-1X4; 1X4
Q1, Q2: MMBT3906; SOT23
R1: 2.2K 1%; 0402
R2, R33: 15K 1%; 0402
R25, R26, R29: NC; 0402
R27, R32: 100K; 0402
R28: 470K; 0402
R30, R31: 2.2R; 0402
T5: AO4407A; SO8
TP-HUB: TP
TP-VBUS: TP
TP_5VP, TP_5VP1: TP
USB2: 61400826021
USB3: 692141030100
USBC: 629722000214
X1: 12MHz; WE-XTAL_CFPX-180

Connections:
+3V3: IC6.19 (V5), IC6.20 (VDD33), R32.1; also elsewhere on the board
+5V: C1.1, C5.1, C22.1, C23.1, C24.1, C25.1, C32.1, IC2.1 (IN), IC7.1 (IN), Q2.2 (E), T5.1 (S), T5.2 (S), T5.3 (S), TP_5VP.TP, TP_5VP1.TP; also elsewhere on the board
CC1: R25.1, USBC.A5 (CC1); also elsewhere on the board
CC2: R26.1, USBC.B5 (CC2); also elsewhere on the board
GND: C1.2, C2.2, C5.2, C6.2, C7.2, C8.2, C21.2, C22.2, C23.2, C24.2, C25.2, C26.2, C27.2, C32.2, C33.2, C34.2, C35.2, D13.3 (GND), D13.8 (GND), D14.3 (GND), D14.8 (GND), D15.3 (GND), D15.8 (GND), D16.3 (GND), D16.8 (GND), IC2.2 (GND), IC6.25 (GND), IC7.2 (GND), JUSB4.4, R1.2, R2.2, R25.2, R26.2, R27.2, R28.2, R29.2, R33.2, USB2.4 (GND), USB2.8 (GND), USB2.S1 (SHIELD), USB2.S2 (SHIELD), USB2.S3 (SHIELD), USB2.S4 (SHIELD), USB3.4 (GND), USB3.7 (GND_DRAIN), USB3.13 (GND), USB3.16 (GND_DRAIN), USB3.S1 (SHIELD), USB3.S2 (SHIELD), USB3.S3 (SHIELD), USB3.S4 (SHIELD), USBC.A1 (GND), USBC.A12 (GND1), USBC.B1 (GND3), USBC.B12 (GND2), USBC.S1 (SHIELD), USBC.S2 (SHIELD), USBC.S3 (SHIELD), USBC.S4 (SHIELD), X1.2 (GND), X1.4 (GND); also elsewhere on the board
HUB1_DP_N: D14.5 (D2-), D14.6 (D2-), IC6.11 (DM1), USB3.11 (D-)
HUB1_DP_P: D14.4 (D2+), D14.7 (D2+), IC6.12 (DP1), USB3.12 (D+)
HUB2_DP_N: D13.4 (D2+), D13.7 (D2+), IC6.9 (DM2), USB2.2 (D-)
HUB2_DP_P: D13.5 (D2-), D13.6 (D2-), IC6.10 (DP2), USB2.3 (D+)
HUB3_DP_N: D13.1 (D1+), D13.10 (D1+), IC6.7 (DM3), USB2.6 (D-)
HUB3_DP_P: D13.2 (D1-), D13.9 (D1-), IC6.8 (DP3), USB2.7 (D+)
HUB4_DP_N: IC6.5 (DM4), JUSB4.2
HUB4_DP_P: IC6.6 (DP4), JUSB4.3
HUB_USB_5V: C33.1, C34.1, C35.1, IC7.6 (OUT), JUSB4.1, TP-HUB.TP, USB2.1 (VBUS), USB2.5 (VBUS)
HUB_XI: C26.1, IC6.4 (XI), X1.1
HUB_XO: C27.1, IC6.3 (XO), X1.3 (2)
unnamed: IC2.5 (ILIM), R2.1
unnamed: C21.1, IC6.16 (!RESET!/CDP)
unnamed: Q1.1 (B), Q1.3 (C), Q2.1 (B), R27.1
unnamed: Q2.3 (C), R28.1, T5.4 (G)
unnamed: IC6.18 (PSELF), R32.2
unnamed: IC6.13 (LED3/SCL), R29.1
unnamed: IC7.5 (ILIM), R33.1
USB3A_DP_N: D16.5 (D2-), D16.6 (D2-), USB3.2 (D-); also elsewhere on the board
USB3A_DP_P: D16.4 (D2+), D16.7 (D2+), USB3.3 (D+); also elsewhere on the board
USB3A_SSRX_N: D16.2 (D1-), D16.9 (D1-), USB3.5 (STDA_SSRX-); also elsewhere on the board
USB3A_SSRX_P: D16.1 (D1+), D16.10 (D1+), USB3.6 (STDA_SSRX+); also elsewhere on the board
USB3A_SSTX_N: D15.4 (D2+), D15.7 (D2+), USB3.8 (STDA_SSTX-); also elsewhere on the board
USB3A_SSTX_P: D15.5 (D2-), D15.6 (D2-), USB3.9 (STDA_SSTX+); also elsewhere on the board
USB3B2_DP_N: IC6.14 (DMU), R31.2
USB3B2_DP_P: IC6.15 (DPU), R30.2
USB3B_DP_N: R31.1; also elsewhere on the board
USB3B_DP_P: R30.1; also elsewhere on the board
USB3B_SSRX_N: D14.1 (D1+), D14.10 (D1+), USB3.14 (STDA_SSRX-); also elsewhere on the board
USB3B_SSRX_P: D14.2 (D1-), D14.9 (D1-), USB3.15 (STDA_SSRX+); also elsewhere on the board
USB3B_SSTX_N: D15.2 (D1-), D15.9 (D1-), USB3.17 (STDA_SSTX-); also elsewhere on the board
USB3B_SSTX_P: D15.1 (D1+), D15.10 (D1+), USB3.18 (STDA_SSTX+); also elsewhere on the board
USB_5V: C6.1, C7.1, C8.1, IC2.6 (OUT), TP-VBUS.TP, USB3.1 (VBUS), USB3.10 (VBUS)
USB_DP_N: USBC.A7 (D-1), USBC.B7 (D-2); also elsewhere on the board
USB_DP_P: USBC.A6 (D+1), USBC.B6 (D+2); also elsewhere on the board
VBUS: C2.1, Q1.2 (E), R1.1, T5.5 (D), T5.6 (D), T5.7 (D), T5.8 (D), USBC.A4 (VBUS), USBC.A9 (VBUS1), USBC.B4 (VBUS3), USBC.B9 (VBUS2)
VBUS_EN: IC2.3 (EN), IC7.3 (EN); also elsewhere on the board

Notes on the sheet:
USB-C POWER CONNECTOR
USB3 CONNECTORS
CURRENT LIMIT SWITCH
4 PORT USB HUB
USB2 CONNECTORS
CURRENT LIMIT SWITCH - HUB


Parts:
C10, C50, C56: 100nF; C0402
C11: 100nF; C1206
C49, C55: 10uF; C0805
D1, D2: TPD4EUSB30; USON
D17, D18, D19, D20, D21, D22, D23: 5Vdc; WE-TVS_DFN1610-2L
ETH1: G16LX-188S7-1G-GO-Y; RJ45-CAT6-POE
IC1: RT9742GGJ; SOT23-5
MICROSD: 693072010801
POE: POE; 2X2
R8, R9: 470R; 0402
TP-VSD: TP

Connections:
+3V3: C55.1, C56.1, ETH1.18, ETH1.20, IC1.5 (IN); also elsewhere on the board
ETH_LEDG: R8.1; also elsewhere on the board
ETH_LEDY: R9.2; also elsewhere on the board
ETH_TX1_N: D2.2 (D1-), D2.9 (D1-), ETH1.TD1-; also elsewhere on the board
ETH_TX1_P: D2.1 (D1+), D2.10 (D1+), ETH1.TD1+; also elsewhere on the board
ETH_TX2_N: D2.4 (D2+), D2.7 (D2+), ETH1.TD2-; also elsewhere on the board
ETH_TX2_P: D2.5 (D2-), D2.6 (D2-), ETH1.TD2+; also elsewhere on the board
ETH_TX3_N: D1.4 (D2+), D1.7 (D2+), ETH1.TD3-; also elsewhere on the board
ETH_TX3_P: D1.5 (D2-), D1.6 (D2-), ETH1.TD3+; also elsewhere on the board
ETH_TX4_N: D1.2 (D1-), D1.9 (D1-), ETH1.TD4-; also elsewhere on the board
ETH_TX4_P: D1.1 (D1+), D1.10 (D1+), ETH1.TD4+; also elsewhere on the board
GND: C10.2, C11.2, C49.2, C50.2, C55.2, C56.2, D1.3 (GND), D1.8 (GND), D2.3 (GND), D2.8 (GND), D17.2 (GND), D18.2 (GND), D19.2 (GND), D20.2 (GND), D21.2 (GND), D22.2 (GND), D23.2 (GND), ETH1.MH3 (SHIELD), ETH1.MH4 (SHIELD), IC1.2 (GND), MICROSD.6 (VSS), MICROSD.S1 (SHIELD), MICROSD.S2 (SHIELD), MICROSD.S3 (SHIELD), MICROSD.S4 (SHIELD); also elsewhere on the board
unnamed: C11.1, ETH1.CT1, ETH1.CT2, ETH1.CT3, ETH1.CT4
unnamed: ETH1.17, R9.1
unnamed: ETH1.19, R8.2
SD_CLK: D21.1 (I/O), MICROSD.5 (CLK); also elsewhere on the board
SD_CMD: D19.1 (I/O), MICROSD.3 (CMD); also elsewhere on the board
SD_DAT0: D22.1 (I/O), MICROSD.7 (DAT0); also elsewhere on the board
SD_DAT1: D23.1 (I/O), MICROSD.8 (DAT1); also elsewhere on the board
SD_DAT2: D17.1 (I/O), MICROSD.1 (DAT2); also elsewhere on the board
SD_DAT3: D18.1 (I/O), MICROSD.2 (CD/DAT3); also elsewhere on the board
SD_PWR: C10.1, C49.1, C50.1, D20.1 (I/O), IC1.1 (OUT), MICROSD.4 (VDD), TP-VSD.TP
SD_PWR_ON: IC1.4 (EN); also elsewhere on the board
TR0_TAP: ETH1.VC1, POE.3
TR1_TAP: ETH1.VC2, POE.1
TR2_TAP: ETH1.VC3, POE.2
TR3_TAP: ETH1.VC4, POE.4

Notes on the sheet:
1000 BASE ETHERNET
MICRO-SD SOCKET


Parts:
3VDC, 3VFB, 5VDC, 5VFB: TP
C9, C36, C37, C42, C43, C44: 100nF; 0402
C38, C45: 33pF; 0402
C39, C46: 22uF 25V; C1206
C40, C41, C47, C48: 22uF - 10V; C1206
C51, C52: 100uF; 100UF-16V
C53: 10uF; C1206
C54: 100nF; C1206
D24: SS54B; SMB
GND: TP
GND-3, GND-5: TP
GPIO: CON-2X20; 2X20
IC3: MP2315GJ-Z; SOT65P280X110-8N
IC8: MP2315S; SOT65P280X110-8N
J5: 694106301002
L2: 4.9uH; SRR5228A
L3: 4.2uH; SRR5228A
LED1, LED3: Green; CHIPLED_0805
R5, R34, R35, R36: 1K; 0402
R6: 0R; 0402
R7: DNI; 0402
R37: NC; 0402
R38, R45: 499K; 0402
R39: 9.09K; 0402
R40, R47: 10R; 0402
R41: 20K; 0402
R42, R49: 40.2K; 0402
R43, R46: 7.5K; 0402
R44, R51: 100K; 0402
R48: 33K; 0402
R50: 12.7K; 0402
SJ1, SJ2, SJ3, SJ4: SOLDERJUMPERNO; SJ_2S-NO
SW, SW3: TP
SW1: 1825027-8; SW2_1825027-C_TEC
T6, T7, T8: BSS138; SOT23
TP-GREF: TP
TP-LED: TP
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

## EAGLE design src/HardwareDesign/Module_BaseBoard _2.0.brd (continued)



Board: 6 copper layers, 160.0 x 105.0 mm, 198 parts (12 on the bottom side), 177 nets.

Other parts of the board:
U$1: ESD_10.00
U$2: OSHW-LOGO-M
U$3: ROHS_LOGO_0.18_IN

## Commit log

2025-01-19 initial creation
    [HW_RPI_10in_Rack.brd, HW_RPI_10in_Rack.sch]
2025-01-21 schematic-baseline finished
    [HW_RPI_10in_Rack.sch]
2025-01-21 add pdf schematics
2025-01-22 add DAQ to design
    [HW_RPI_10in_Rack.sch, HW_RPI_DAQ.brd, HW_RPI_DAQ.sch]
2025-01-24 create PCB
    [HW_RPI_DAQ.brd, HW_RPI_DAQ.sch, c-2489108-1-1-2d.dxf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]
2025-01-24 3D render
    [HW_RPI_DAQ.brd, HW_RPI_DAQ.sch]
2025-01-25 update schematics with new testpoints
    [HW_RPI_10in_Rack.brd, HW_RPI_10in_Rack.sch, HW_RPI_DAQ.brd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]
2025-01-25 update PDF schematics
    [HW_RPI_DAQ.brd, HW_RPI_DAQ.sch, c-2489108-1-1-2d.dxf]
2025-02-05 add documentation
    [Dataforge-Pi.brd, Dataforge-Pi.sch, Module_AIO.sch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]
2025-02-07 AIO Board ready
    [Module_AIO.brd, Module_AIO.sch, Pinouts.xlsx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]
2025-02-08 finish DIO card desing
    [Module_AIO.brd, Module_AIO.sch, Module_DIO.brd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]
2025-02-08 Baseboard design ready
    [Dataforge-Pi.brd, Dataforge-Pi.sch, Module_DIO.sch]
2025-02-09 finish PCB desing
    [BLANK_MeasurementModule.brd, Module_AIO.brd, Module_AIO_bottom_bom.csv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]
2025-02-10 add diffpaircheck
    [Module_BaseBoard.brd, Module_BaseBoard.sch]
2025-03-02 Redesign to reduce height
    [BLANK_MeasurementModule.brd, Module_AIO.brd, Module_AIO.sch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]

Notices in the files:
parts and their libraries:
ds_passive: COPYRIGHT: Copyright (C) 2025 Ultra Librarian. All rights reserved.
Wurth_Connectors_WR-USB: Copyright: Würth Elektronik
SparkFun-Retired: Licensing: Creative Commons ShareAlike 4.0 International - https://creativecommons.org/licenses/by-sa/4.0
